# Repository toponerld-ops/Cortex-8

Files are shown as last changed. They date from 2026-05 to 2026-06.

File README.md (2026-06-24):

<div align="center">

# **Cortex-8**

**8-in-1 AIO Flight Controller for X8 Coaxial Racing Drones**

**High-performance X8 coaxial FPV racing drone flight controller**  everything integrated on a single 61×65mm board.

</div>

---

ZINE-Cortex-8

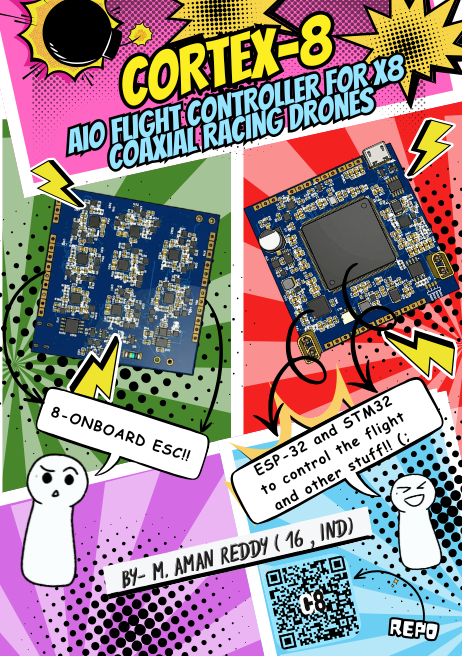
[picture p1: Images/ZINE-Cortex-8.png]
ZINE


## *Project Visionnnn*

This is Gen 5 of my custom flight controller journey.
I keep building these things because I genuinely want to see how far one guy can push drone hardware before reality kicks in. The long-term plan is straightforward: design flight controllers from scratch, cram every possible subsystem onto one tiny board, and eventually move into AI-powered autonomous flight (the "drones that think for themselves" thing is just too cool no Skynet though, promise).
Cortex-8 is the latest step in that direction a completely over-the-top 8-in-1 All-In-One flight controller built specifically for X8 coaxial FPV racing drones.

## *Features*

MCU: STM32H743 running at 480MHz

Wireless: ESP32-S3 (WiFi + BLE + ELRS support)

ESCs: 8x integrated high-current drivers for X8 coaxial setup

Battery: Dual 2S LiPo with software + hardware switchable series/parallel (7.4V or 14.8V)

Charging: Up to 140W USB-PD EPR at 20V

Blackbox: 128MB QSPI flash

PCB: 61×65mm 8-layer HDI, ENIG finish, X-Ray inspected

Bonus: Built-in crash locator so you’ll (hopefully) never lose the drone

---

BOM

|No.|Quantity|Comment |Designator |Footprint |Value |Manufacturer Part |Manufacturer |Supplier Part|Supplier|JLCPCB Price|JLCPCB Stock|
|---|---|---|---|---|---|---|---|---|---|---|---|
|1  |84 |100nF |C1,C2,C5,C6,C8,C9,C10,C14,C15,C16,C17,C18,C19,C20,C21,C23,C25,C26,C29,C30,C31,C32,C33,C37,C39,C41,C43,C45,C47,C49,C51,C53,C55,C57,C59,C61,C63,C65,C67,C69,C72,C74,C76,C77,C79,C80,C81,C85,C87,C88,C89,C93,C95,C96,C97,C101,C103,C104,C105,C109,C110,C111,C115,C117,C118,C119,C123,C125,C126,C127,C131,C133,C134,C135,C139,C140,C156,C158,C159,C161,C162,C163,C164,C166|C0603 |100nF |CC0603KRX7R9BB104 |YAGEO(国巨) |C14663 |LCSC |0.0026 |14950789 |
|2  |7 |1uF |C3,C7,C35,C36,C38,C73,C75 |C0402 |1uF |0402X105K250NT |FH(风华) |C967571 |LCSC |0.0018 |91670 |
|3  |4 |2.2uF |C4,C11,C12,C71 |C0603 |2.2uF |CL10A225KO8NNNC |SAMSUNG(三星) |C23630 |LCSC |0.0014 |1034471 |
|4  |1 |220uF |C13 |CAP-SMD_BD8.0-L8.3-W8.3-LS9.3-FD |220uF |RVT220UF35V67RV0024 |KNSCHA(科尼盛) |C2836441 |LCSC |0.012 |81517 |
|5  |2 |47uF |C22,C24 |C0603 |47uF  |GRM188R60J476ME15D |muRata(村田) |C140782 |LCSC |0.0212 |194067 |
|6  |39 |10uF |C27,C28,C34,C40,C42,C44,C46,C48,C50,C52,C54,C56,C58,C60,C62,C64,C66,C68,C70,C78,C86,C94,C102,C116,C124,C132,C141,C142,C143,C144,C145,C146,C149,C150,C151,C154,C157,C160,C165 |C0805 |10uF  |GRM21BR71E106KEBHL |muRata(村田) |C5299751 |LCSC |0.0243 |1523 |
|7  |24 |10nF |C82,C83,C84,C90,C91,C92,C98,C99,C100,C106,C107,C108,C112,C113,C114,C120,C121,C122,C128,C129,C130,C136,C137,C138 |C0603 |10nF  |CC0603KRX7R9BB103 |YAGEO(国巨) |C100042 |LCSC |0.0009 |17534 |
|8  |3 |47nF |C147,C148,C153 |C0402 |47nF  |0402B473K100CT |Walsin(华新科) |C301947 |LCSC |0.0005 |15 |
|9  |1 |4.7uF |C152 |C0603 |4.7uF |CL10A475KP8NNNC |SAMSUNG(三星) |C1705 |LCSC |0.0019 |96271 |
|10 |1 |2.2uF |C155 |C0603 |2.2uF |CC0603X5R25V225KN |TORCH(火炬) |C53084536 |LCSC |0.0031 |26321 |
|11 |2 |XT30UPB-M |CN1,CN2 |CONN-TH_XT30UPB-M | |XT30UPB-M |AMASS(艾迈斯) |C428721 |LCSC |0.0388 |59450 |
|12 |1 |SMBJ15A |D1 |SMB_L4.6-W3.6-LS5.3-RD | |SMBJ15A |Hottech(合科泰) |C49238213 |LCSC |0.0042 |2414 |
|13 |2 |PRTR5V0U2X |D4,D7 |SOT-143_L2.9-W1.3-P1.92-LS2.3-BL | |PRTR5V0U2X |GOODWORK(固得沃克) |C21713980 |LCSC |0.0068 |9185 |
|14 |1 |SMBJ24A |D6 |SMB_L4.5-W3.7-LS5.4-RD | |SMBJ24A |FOSAN(富捷/富信) |C5353267 |LCSC |0.0061 |6752 |
|15 |1 |HX PZ1.27-1x4P WT |H1 |HDR-SMD_4P-P1.27-H-M-W7.8 | |HX PZ1.27-1x4P WT |hanxia(韩下) |C46061654 |LCSC |0.0118 |4282 |
|16 |1 |SCBW100505U100T |L1 |L0402 | |SCBW100505U100T |Yanchuang(研创) |C53063739 |LCSC |0.0006 |10000 |
|17 |2 |2.2uH |L2,L3 |IND-SMD_L4.0-W4.0_LQH44PN2R2MP0L |2.2uH |SMNR4020-2.2UH |SXN(顺翔诺) |C135262 |LCSC |0.0087 |51409 |
|18 |1 |4.7uH |L4 |L0603 |4.7uH |CKCW0603H-4.7uH/K |CENKER(岑科) |C19188762 |LCSC |0.0118 |1569 |
|19 |1 |1uH |L5 |IND-SMD_L2.0-W1.6_MTQH201610S |1uH |APH201612C1R0MP01 |APV(爱普微) |C42455319 |LCSC |0.007 |2205 |
|20 |1 |16MHz |OSC1 |OSC-SMD_4P-L3.2-W2.5_OW2EL89CANUNFAYLC|16MHz |OW2EL89CENUXFMYLC-16M |YXC(扬兴晶振) |C22434891 |LCSC |0.1652 |2407 |
|21 |54 |CSD17313Q2 |Q1,Q2,Q3,Q4,Q5,Q6,Q7,Q10,Q11,Q12,Q13,Q14,Q15,Q16,Q17,Q18,Q19,Q20,Q21,Q22,Q23,Q24,Q25,Q26,Q27,Q28,Q29,Q30,Q31,Q32,Q33,Q34,Q35,Q36,Q37,Q38,Q39,Q40,Q41,Q42,Q43,Q44,Q45,Q46,Q47,Q48,Q49,Q50,Q51,Q52,Q53,Q54,Q55,Q56 |WSON-6_L2.0-W2.0-P0.65-TL_CSD17313Q2  | |CSD17313Q2 |TI(德州仪器) |C2863837 |LCSC |0.0495 |7352 |
|22 |1 |2N7002 |Q8 |SOT-23-3_L2.9-W1.5-P1.90-LS2.6-BR | |2N7002 |TECH PUBLIC(台舟) |C28646312 |LCSC |0.0033 |3290 |
|23 |1 |SI2323DS(UMW) |Q9 |SOT-23-3_L2.9-W1.3-P0.95-LS2.4-BR | |SI2323DS(UMW) |UMW(友台半导体) |C5346821 |LCSC |0.0078 |12554 |
|24 |1 |560kΩ |R1 |R0603 |560kΩ |RC0603FR-07560KL |YAGEO(国巨) |C137699 |LCSC |0.0003 |109432 |
|25 |2 |10kΩ |R2,R9 |R0402 |10kΩ  |AC0402FR-0710KL |YAGEO(国巨) |C144807 |LCSC |0.0003 |132 |
|26 |6 |22Ω |R3,R4,R5,R6,R7,R8 |R0402 |22Ω |RC0402FR-0722RL |YAGEO(国巨) |C114765 |LCSC |0.0002 |124 |
|27 |1 |267kΩ |R10 |R0603 |267kΩ |FRC0603F2673TS |FOJAN(富捷) |C2998118 |LCSC |0.0003 |26827 |
|28 |7 |100kΩ |R11,R16,R17,R21,R125,R126,R131 |R0402 |100kΩ |RC0402FR-07100KL |YAGEO(国巨) |C60491 |LCSC |0.0002 |5492 |
|29 |1 |10Ω |R12 |RES-SMD_L5.8-W2.2 |10Ω |SMM02070C1009FBP00 |VISHAY(威世) |C5224088 |LCSC |0.0221 |2519 |
|30 |2 |10mΩ |R13,R14 |R0805 |10mΩ  |HoJLR0805-1/2W-10mR-1%|Milliohm(毫欧) |C41427589 |LCSC |0.0064 |3107 |
|31 |7 |10kΩ |R15,R118,R119,R123,R124,R132,R133 |R0402 |10kΩ  |RC0402FR-0710KL |YAGEO(国巨) |C60490 |LCSC |0.0002 |4 |
|32 |3 |100Ω |R18,R19,R20 |R0402 |100Ω  |RC0402FR-07100RL |YAGEO(国巨) |C106232 |LCSC |0.0002 |33 |
|33 |48 |10kΩ |R22,R23,R24,R25,R26,R27,R34,R35,R36,R37,R38,R39,R46,R47,R48,R49,R50,R51,R58,R59,R60,R61,R62,R63,R70,R71,R72,R73,R74,R75,R82,R83,R84,R85,R86,R87,R94,R95,R96,R97,R98,R99,R106,R107,R108,R109,R110,R111 |R0402 |10kΩ  |CR0402FF1002G |LIZ(丽智电子) |C100196 |LCSC |0.0002 |3518 |
|34 |48 |2.2Ω |R28,R29,R30,R31,R32,R33,R40,R41,R42,R43,R44,R45,R52,R53,R54,R55,R56,R57,R64,R65,R66,R67,R68,R69,R76,R77,R78,R79,R80,R81,R88,R89,R90,R91,R92,R93,R100,R101,R102,R103,R104,R105,R112,R113,R114,R115,R116,R117 |R0402 |2.2Ω  |RMC04022.21%N |Tyohm(幸亚电阻) |C325532 |LCSC |0.0006 |585 |
|35 |2 |15kΩ |R120,R121 |R0402 |15kΩ  |RC0402FR-0715KL |YAGEO(国巨) |C114761 |LCSC |0.0002 |2846 |
|36 |1 |6.04kΩ |R122 |R0402 |6.04kΩ|FRC0402F6041TS |FOJAN(富捷) |C2998182 |LCSC |0.0003 |105693 |
|37 |1 |100Ω |R127 |R0402 |100Ω  |0402WGJ0101TCE |UNI-ROYAL(厚声) |C25138 |LCSC |0.0002 |8 |
|38 |1 |2.2kΩ |R128 |R0402 |2.2kΩ |0402WGJ0222TCE |UNI-ROYAL(厚声) |C25933 |LCSC |0.0002 |24 |
|39 |1 |294Ω |R129 |R0402 |294Ω  |0402WGF2940TCE |UNI-ROYAL(厚声) |C270618 |LCSC |0.0002 |2875 |
|40 |1 |127kΩ |R130 |R0805 |127kΩ |FRC0805F1273TS |FOJAN(富捷) |C2974033 |LCSC |0.0005 |133787 |
|41 |3 |Test-Point |TP1,TP2,TP3 |Test-Point-0.5mm | | | | | | | |
|42 |1 |STM32H743BIT6 |U1 |LQFP-208_L28.0-W28.0-P0.50-LS30.0-BL  | |STM32H743BIT6 |ST(意法半导体) |C89418 |LCSC |1.9319 |205 |
|43 |1 |W25Q128JWSIQ |U2 |SOIC-8_L5.3-W5.3-P1.27-LS8.0-BL | |W25Q128JWSIQ |Winbond(华邦) |C2763561 |LCSC |0.6874 |468 |
|44 |1 |ICM-42688-P |U3 |LGA-14_L3.0-W2.5-P0.50-TL | |ICM-42688-P |TDK InvenSense(应美盛)|C1850418 |LCSC |2.1188 |2886 |
|45 |1 |ICM-20602 |U4 |LGA-16_L3.0-W3.0-P0.50-BL | |ICM-20602 |TDK InvenSense(应美盛)|C97633 |LCSC |0.927 |8778 |
|46 |1 |74LVC1G08GV |U5 |SOT-23-5_L3.0-W1.7-P0.95-LS2.8-BL | |74LVC1G08GV |MDD(辰达半导体) |C53185136 |LCSC |0.0106 |2962 |
|47 |1 |74LVC1G04GV |U6 |SOT-23-5_L2.9-W1.6-P0.95-LS2.7-BR | |74LVC1G04GV |TECH PUBLIC(台舟) |C19829589 |LCSC |0.008 |5360 |
|48 |1 |TLV3201AIDCKT |U7 |SOT-353_L2.0-W1.2-P0.65-LS2.1-BL-1 | |TLV3201AIDCKT |TI(德州仪器) |C133590 |LCSC |0.0523 |139 |
|49 |1 |LM4040C25FTA |U8 |SOT-23-3_L2.9-W1.3-P1.90-LS2.4-BR | |LM4040C25FTA |DIODES(美台) |C460607 |LCSC |0.0625 |622 |
|50 |2 |LM74610QDGKRQ1 |U9,U10 |VSSOP-8_L3.0-W3.0-P0.65-LS5.0-BL | |LM74610QDGKRQ1 |TI(德州仪器) |C2649431 |LCSC |0.229 |1900 |
|51 |2 |INA240A2PW |U11,U12 |TSSOP-8_L4.4-W3.0-P0.65-LS6.4-BR | |INA240A2PW |TI(德州仪器) |C1346461 |LCSC |0.5124 |2 |
|52 |1 |TPS62840DLCR |U13 |VSON-8_L2.0-W1.5-P0.50-BL | |TPS62840DLCR |TI(德州仪器) |C2071859 |LCSC |0.2608 |69 |
|53 |1 |TPS62170QDSGTQ1 |U14 |WSON-8_L2.0-W2.0-P0.50-TL-EP | |TPS62170QDSGTQ1 |TI(德州仪器) |C2071903 |LCSC |0.2846 |90 |
|54 |1 |TPS3840PL33DBVR |U15 |SOT-23-5_L2.9-W1.6-P0.95-LS2.8-BR | |TPS3840PL33DBVR |TI(德州仪器) |C6290353 |LCSC |0.2382 |85 |
|55 |1 |SM02B-GHS-TB(LF)(SN) |U16 |CONN-SMD_SM02B-GHS-TB-LF-SN | |SM02B-GHS-TB(LF)(SN)  |JST |C189893 |LCSC |0.0219 |5447 |
|56 |8 |FD6288Q |U17,U18,U19,U20,U21,U22,U23,U24 |QFN-24_L4.0-W4.0-P0.50-BL-EP2.6 | |FD6288Q |Fortior Tech(峰岹) |C328453 |LCSC |0.1281 |972 |
|57 |1 |CH224K |U25 |ESSOP-10_L4.9-W3.9-P1.0-LS6.0-TL-EP | |CH224K |WCH(南京沁恒) |C970725 |LCSC |0.0913 |10052 |
|58 |1 |BQ25798RQMR |U26 |QFN-29_L4.0-W4.0-P0.40-TL-BQ25792RQMR | |BQ25798RQMR |TI(德州仪器) |C2876593 |LCSC |0.4014 |5387 |
|59 |1 |ESP32-S3FN8 |U27 |QFN-56_L7.0-W7.0-P0.40-TL-EP4.0 | |ESP32-S3FN8 |ESPRESSIF(乐鑫) |C2913196 |LCSC |0.5269 |1714 |
|60 |1 |TYPE-C 16PIN 3MD(385)|USB1 |USB-C-SMD_TYPE-C16PIN | |TYPE-C 16PIN 3MD(385) |SHOU HAN(首韩) |C2858270 |LCSC |0.0193 |28089 |

# Cortex-8 Firmware

The Cortex-8 runs on Betaflight 4.5.x, but it features a custom target that I developed specifically for the stm32h743. If you're interested in checking it out, you can find the complete target in /firmware/targets/CORTEX8/.

## Building the Firmware (For Windows)

# Clone Betaflight
git clone https://github.com/betaflight/betaflight
cd betaflight

# Copy Cortex-8 target into the source tree
cp -r /path/to/Cortex-8/firmware/targets/CORTEX8 src/main/target/CORTEX8

# Build
make CORTEX8

After this, the compiled .hex file will be located in the obj/ directory.

### Flashing

**Using SWD (recommended for the first flash):**
1. Connect the st-link v2/v3 to the 4 pin 1.27mm SWD header on the top layer.
2. The pinout is vcc — swdio — swclk — gnd.
3. Open STM32CubeProgrammer.
4. Connect via st-link.
5. Load the hex file and click program.

**Using DFU (for any subsequent flashes):**
1. Hold boot0 to 3.3v while plugging in USB-C.
2. The board will appear as STM32 bootloader in Device Manager.
3. Open Betaflight Configurator's firmware flasher.
4. Load CORTEX8.hex and flash it.
It’s much faster once the bootloader is already installed.
---

### How to Assemble the Cortex-8 FC

# *Step-by-Step*

Manufacture the PCB,
Upload the gerbers from the /gerbers folder to JLCPCB.

Order Components,
Order the components using BOM provided.

Flash the Firmware,
First, connect the SWD pins of the STM32 to a FTDI flasher. flash via SWD, then you can use DFU for updates. Set the board target as custom STM32H743 in Betaflight.

Batteries & Power,
- **PRECAUTION:Before connecting the battery check your surroundings for safty**
  
Connect the two 2S LiPos using XT30. The board starts in parallel (7.4V) by default. The STM32 can switch to series (14.8V), but there’s a hardware interlock to stop accidental shorting of the batteries. USB-PD charging is handled automatically.

Motors,
Solder 20AWG silicone wire to the phase pads on the edges (3 pads per motor). Left side = M1/M3/M5/M7, right side = M2/M4/M6/M8.

FPV & Extras,
The OpenFPV camera fits on the 30.5×30.5mm holes. The crash locator uses a small backup battery and sends BLE beacons via the ESP32 when the main power is lost.

## **IMAGES**

TOP PCB 3D

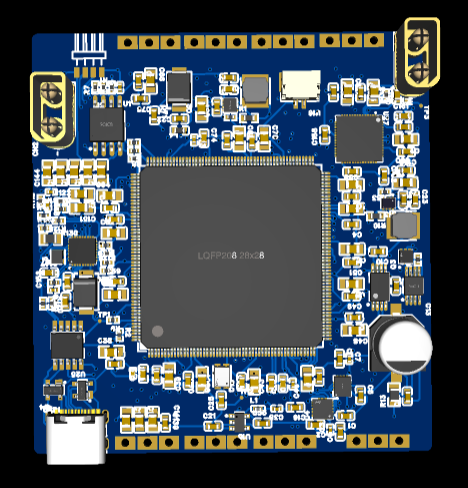
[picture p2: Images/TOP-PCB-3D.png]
TOP-PCB-3D


BOTTOM PCB 3D

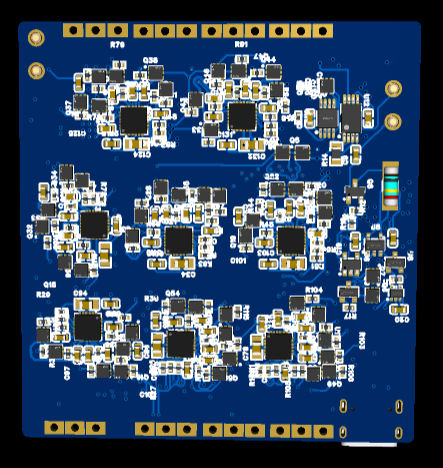
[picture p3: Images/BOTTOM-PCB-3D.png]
BOTTOM-PCB-3D


TOP LAYER TRACE

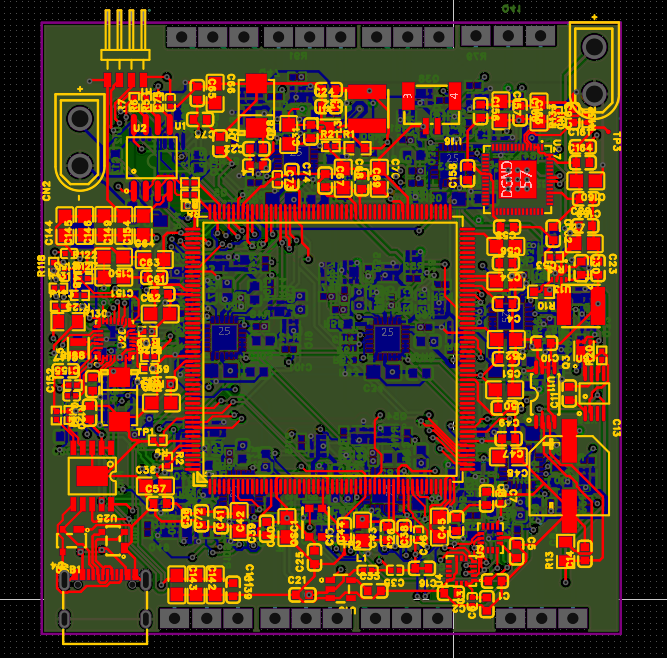
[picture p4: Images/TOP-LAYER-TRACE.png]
TOP-LAYER-TRACE


INNER LAYER 1

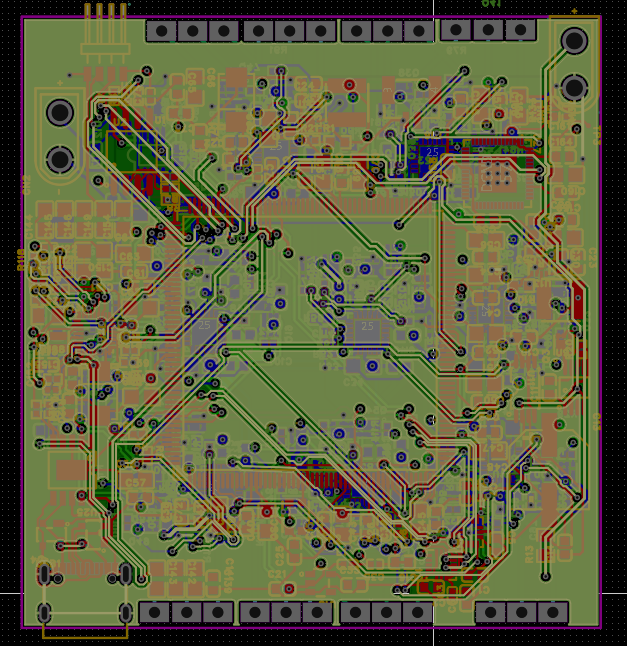
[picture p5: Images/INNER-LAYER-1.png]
INNER-LAYER-1


INNER LAYER 2

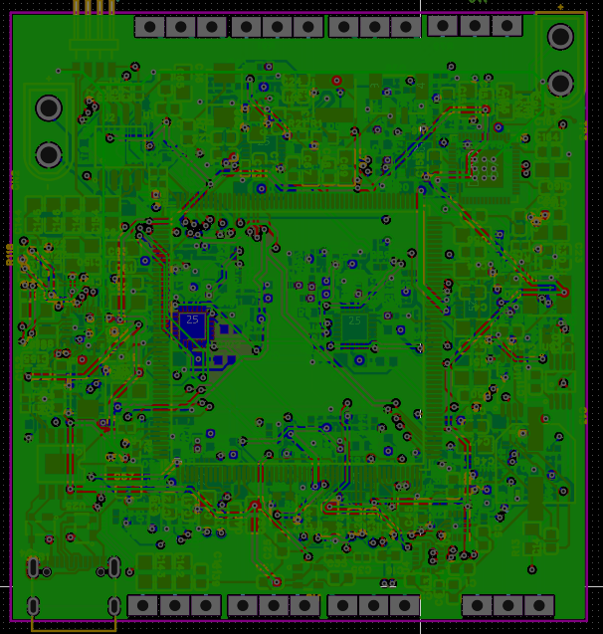
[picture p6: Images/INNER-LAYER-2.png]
INNER-LAYER-2


INNER LAYER 3

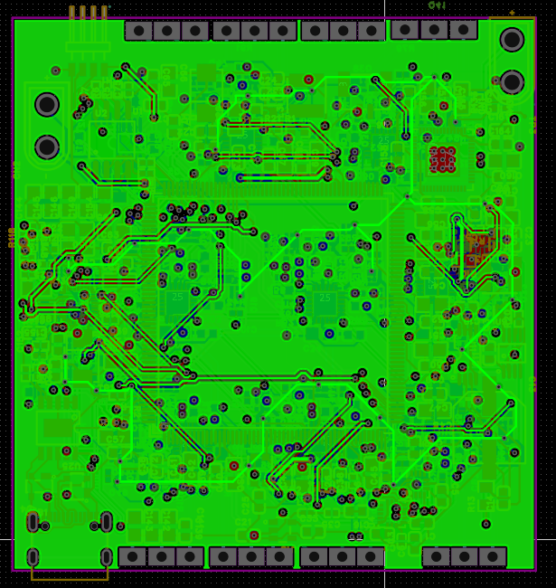
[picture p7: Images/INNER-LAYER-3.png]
INNER-LAYER-3


INNER LAYER 4

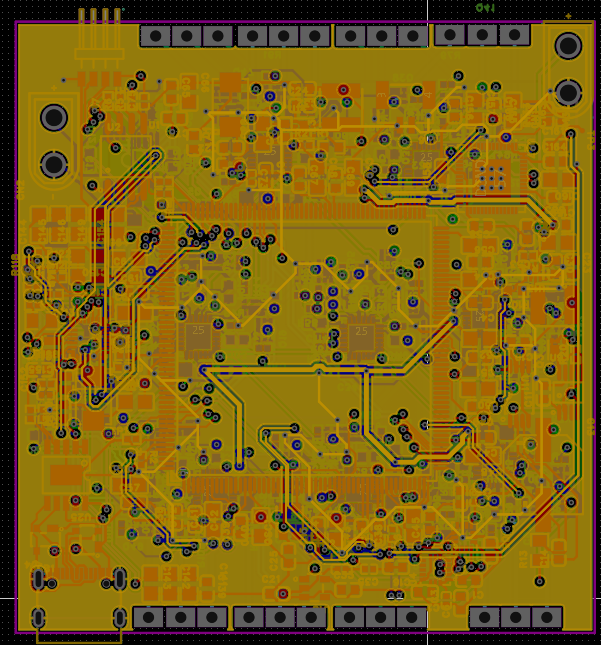
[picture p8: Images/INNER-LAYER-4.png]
INNER-LAYER-4


INNER LAYER 5

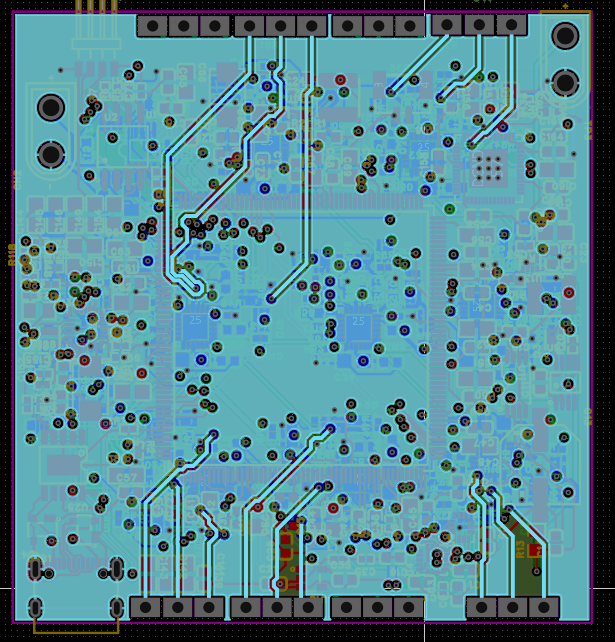
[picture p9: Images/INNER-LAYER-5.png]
INNER-LAYER-5


INNER LAYER 6

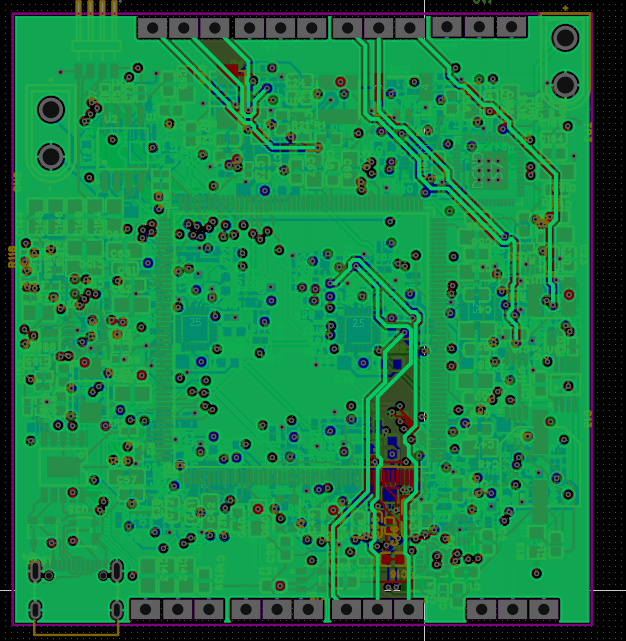
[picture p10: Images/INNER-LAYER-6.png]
INNER-LAYER-6


BOTTOM LAYER TRACE

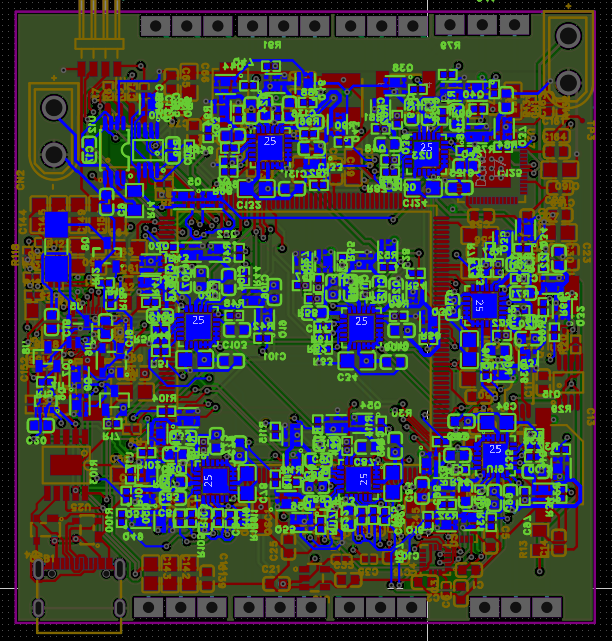
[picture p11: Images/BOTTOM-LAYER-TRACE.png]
BOTTOM-LAYER-TRACE


Designed by Muduganti Aman Reddy | Hackclub

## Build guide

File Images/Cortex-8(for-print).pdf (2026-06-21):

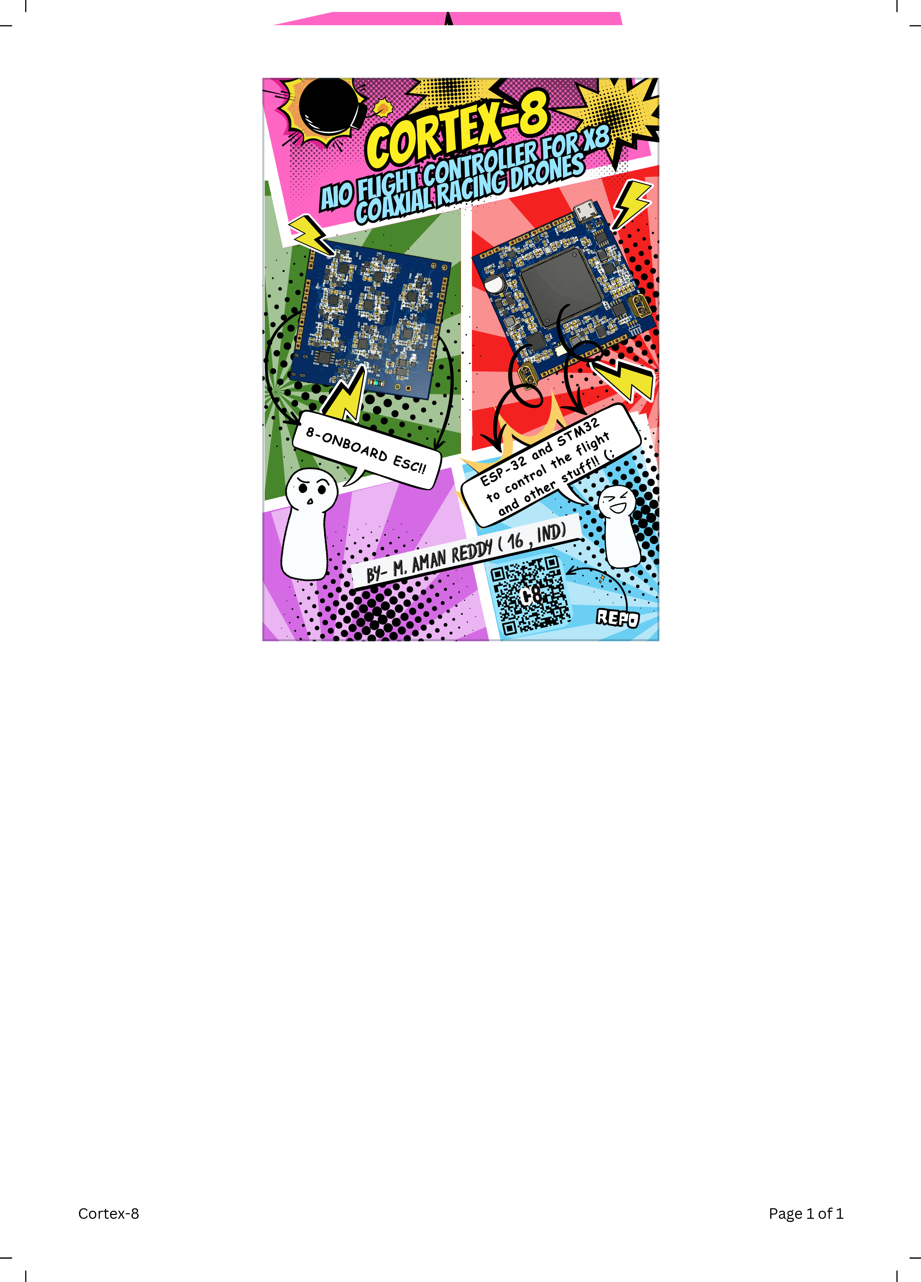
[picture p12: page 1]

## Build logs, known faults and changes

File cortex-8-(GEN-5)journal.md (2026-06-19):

# CORTEX-8 — Journal Export

- Exported at: 2026-06-19T15:39:32Z
- Project ID: 1067
- Entries: 63

## Entry 1
- ID: 1228
- Author: toponerld
- Created At: 2026-04-05T12:04:29Z

### Content

soo started the sch of the board and did sm researchig i have a few probs that ill fix later made sm progress
Screenshot 2026-04-05 172329.png

### Recording Links

- https://public.lapse-hackclub.link/timelapses/6jMfzRBHHVCS/timelapse-6jMfzRBHHVCS.mp4

## Entry 2
- ID: 1638
- Author: toponerld
- Created At: 2026-04-10T06:05:55Z

### Content

i cross checked the pins and analysed the max out put and the size charts so that i can fit all my components i had multiple windows open and cld share only one will check the next journal have to do bit more research


### Recording Links

- https://public.lapse-hackclub.link/timelapses/5mZUVrlAqrgS/timelapse-5mZUVrlAqrgS.mp4

## Entry 3
- ID: 1640
- Author: toponerld
- Created At: 2026-04-10T06:58:35Z

### Content

soooo umm i almost completed joting all the pins of the esp32 since im doin the pcb on a very tight space which also includes 8 escs so deciding where everything shd go in the final pcb next is the stm. its a random ss idk wt to put


### Recording Links

- https://public.lapse-hackclub.link/timelapses/4FbfQcJ-V51w/timelapse-4FbfQcJ-V51w.mp4

## Entry 4
- ID: 1757
- Author: toponerld
- Created At: 2026-04-11T11:01:01Z

### Content

making the sch for the fc, took sm time to understand how to Add Hierarchical Labels eventually figured it out and to clarify in the lapse when u see my cursor just moving here and there i was adding net lables but since when u open sch settings it opens in an another window 


### Recording Links

- https://public.lapse-hackclub.link/timelapses/PoMJecg4o_60/timelapse-PoMJecg4o_60.mp4

## Entry 5
- ID: 1779
- Author: toponerld
- Created At: 2026-04-11T16:24:34Z

### Content

i switched to easyeda forr better library's and im new to that shi so gonna take some time to adjust to it so started the sch again
Screenshot 2026-04-11 215417.png

### Recording Links

- https://public.lapse-hackclub.link/timelapses/MAulKlX61qXN/timelapse-MAulKlX61qXN.mp4

## Entry 6
- ID: 1795
- Author: toponerld
- Created At: 2026-04-11T18:04:23Z

### Content

sooo i almost completed the battery block this is taking a lot more time than i expected so for tomorrow ill try to finish atleast half of it kinda getting used to it but looking at the data sheets is taking time too
Screenshot 2026-04-11 233402.png

### Recording Links

- https://public.lapse-hackclub.link/timelapses/4zrOwDMnkmM1/timelapse-4zrOwDMnkmM1.mp4

## Entry 7
- ID: 1801
- Author: toponerld
- Created At: 2026-04-11T18:42:19Z

### Content

sooo i did most of the connections it was a bit confusing but i figured it out using the data sheets im glad i switched to easyeda now all thats left is to connect the power block to the stm32
Screenshot 2026-04-12 001153.png

### Recording Links

- https://public.lapse-hackclub.link/timelapses/mEVI3-77TItn/timelapse-mEVI3-77TItn.mp4

## Entry 8
- ID: 1812
- Author: toponerld
- Created At: 2026-04-11T19:44:54Z

### Content

completed the battery block had a bit of confusion with the xt30 connectors and the net ports but figured everything and its done
Screenshot 2026-04-12 011443.png

### Recording Links

- https://public.lapse-hackclub.link/timelapses/j6-ipeWDboKf/timelapse-j6-ipeWDboKf.mp4

## Entry 9
- ID: 3175
- Author: toponerld
- Created At: 2026-04-21T08:51:28Z

### Content

ummm so i finished placing most of my components but most of them were out of stock and had to find replacements and look at their data sheets and i accidentally clicked end instead of resume  
Screenshot 2026-04-21 142104.png

### Recording Links

- https://public.lapse-hackclub.link/timelapses/ANK_b-zQlaBn/timelapse-ANK_b-zQlaBn.mp4

## Entry 10
- ID: 3187
- Author: toponerld
- Created At: 2026-04-21T10:21:38Z

### Content


did sm wiring and checked the data sheets for the next steps imma check more of the pins later and thats it

## Entry 11
- ID: 3524
- Author: toponerld
- Created At: 2026-04-23T07:31:21Z

### Content

did alot of research in call with krish and did a lot more research for the ground station for the drone ig its gonna take a lot of money for the groundstation 

idk what ss to keep for research

### Recording Links

- https://public.lapse-hackclub.link/timelapses/vDA6t_Qalmu5/timelapse-vDA6t_Qalmu5.mp4

## Entry 12
- ID: 9290
- Author: toponerld
- Created At: 2026-05-26T04:45:05Z

### Content

started the power block its soooo confusing but ill have to pull through wish me luckk hope ill complete this soon
Screenshot 2026-05-26 101445.png

### Recording Links

- https://public.lapse-hackclub.link/timelapses/wyykcDoh7P_6/timelapse-wyykcDoh7P_6.mp4
- https://public.lapse-hackclub.link/timelapses/fHQlYi5-aYEJ/timelapse-fHQlYi5-aYEJ.mp4

## Entry 13
- ID: 9332
- Author: toponerld
- Created At: 2026-05-26T10:58:43Z

### Content

I just realised that changing the value of a cap or a resistor or anything will not change its footprint now i have to change every resistor cap and inductor i placed wish me luck 
Screenshot 2026-05-26 162814.png
Screenshot 2026-05-26 154131.png
Screenshot 2026-05-26 155002.png

### Recording Links

- https://public.lapse-hackclub.link/timelapses/nekmbHjiDxzb/timelapse-nekmbHjiDxzb.mp4

## Entry 14
- ID: 9619
- Author: toponerld
- Created At: 2026-05-27T10:03:31Z

### Content

sooo ive updated all the resistors inductors and caps every part now finnaly they have a footprint this was a huge lesson here are the ss for all the parts i replaced 
Screenshot 2026-05-27 140556.png
ohh looks like i cant paste 14 screenshots

### Recording Links

- https://public.lapse-hackclub.link/timelapses/bVV5VfXSvdcb/timelapse-bVV5VfXSvdcb.mp4

## Entry 15
- ID: 9625
- Author: toponerld
- Created At: 2026-05-27T10:51:46Z

### Content

I finished the battery block and the power block now im starting the ecs block which contains 8 gate drivers!! and 48x CSD17313Q2 motor FETs.!!

Screenshot 2026-05-27 162105.png
Screenshot 2026-05-27 162059.png
Screenshot 2026-05-27 162052.png

### Recording Links

- https://public.lapse-hackclub.link/timelapses/EtGdO5alh2ek/timelapse-EtGdO5alh2ek.mp4

## Entry 16
- ID: 9867
- Author: toponerld
- Created At: 2026-05-28T09:26:53Z

### Content

hmmm im a bit confused about the connections from the gate drivers to the fets and ive asked my friends too but none of dont seem to figure it out,hmmm have to do a bit more resarch on this


### Recording Links

- https://public.lapse-hackclub.link/timelapses/1SuL4X-1erth/timelapse-1SuL4X-1erth.mp4

## Entry 17
- ID: 9911
- Author: toponerld
- Created At: 2026-05-28T14:03:22Z

### Content

sooo i understood what i was doin wrong with the help of krish the goat!! so i was connecting 2 mosfets together instead of connecting them to the driver but fixed it!!
Screenshot 2026-05-28 193307.png

### Recording Links

- https://public.lapse-hackclub.link/timelapses/823QmB8zUmb-/timelapse-823QmB8zUmb-.mp4

## Entry 18
- ID: 9920
- Author: toponerld
- Created At: 2026-05-28T14:39:42Z

### Content

yeye ive almost completed the esc block and now i have 48 fets and 8 FD6288Q gate drivers so ive wired everything up and thats it for the ecs block next is the usb block
Screenshot 2026-05-28 200904.png
 but have to change the lables too

### Recording Links

- https://public.lapse-hackclub.link/timelapses/KEnmi0Q4PW4_/timelapse-KEnmi0Q4PW4_.mp4

## Entry 19
- ID: 9924
- Author: toponerld
- Created At: 2026-05-28T15:16:08Z

### Content

okay sooo the blk 5 is finished!!!!! ive finished the lables and now gonna start the blk 6 the usb block!!
Screenshot 2026-05-28 203700.png

### Recording Links

- https://public.lapse-hackclub.link/timelapses/n1dugfq_AvVL/timelapse-n1dugfq_AvVL.mp4

## Entry 20
- ID: 10209
- Author: toponerld
- Created At: 2026-05-29T18:14:24Z

### Content

yesterday i finished the blk 5 the esc so in this session i started the block 6 the usb block and placed almost every component i need next up is wiring 
Screenshot 2026-05-29 234407.png

### Recording Links

- https://public.lapse-hackclub.link/timelapses/JiXwQSWwBEa1/timelapse-JiXwQSWwBEa1.mp4

## Entry 21
- ID: 10351
- Author: toponerld
- Created At: 2026-05-30T09:04:37Z

### Content

looks like the parts i place were wrong so placing finding good alternatives and placing them all again 
Screenshot 2026-05-30 143423.png

### Recording Links

- https://public.lapse-hackclub.link/timelapses/gB0-7IEDqoTO/timelapse-gB0-7IEDqoTO.mp4

## Entry 22
- ID: 10360
- Author: toponerld
- Created At: 2026-05-30T10:33:17Z

### Content

started wriring the block 6 i do have sm confusion tho but will look into it w=hope ill finish this sooon 
Screenshot 2026-05-30 160214.png

### Recording Links

- https://public.lapse-hackclub.link/timelapses/qN2kBCENBClz/timelapse-qN2kBCENBClz.mp4

## Entry 23
- ID: 10463
- Author: toponerld
- Created At: 2026-05-30T17:58:36Z

### Content

so ive started wiring for the usb c in the BLK 6 ig i will finish the BLK 6 in the next session or in the next 2 sessions 
Screenshot 2026-05-30 232823.png

### Recording Links

- https://public.lapse-hackclub.link/timelapses/VK8As-OSBlEh/timelapse-VK8As-OSBlEh.mp4

## Entry 24
- ID: 10483
- Author: toponerld
- Created At: 2026-05-30T18:45:08Z

### Content

sooo did the main connections and looks like mass ngl but imm having doubts whether im doin this ryt i was disscussin with my friend and found new info 
Screenshot 2026-05-31 001448.png

### Recording Links

- https://public.lapse-hackclub.link/timelapses/m7vXRtY4G0Da/timelapse-m7vXRtY4G0Da.mp4

## Entry 25
- ID: 10614
- Author: toponerld
- Created At: 2026-05-31T08:33:22Z

### Content

finished block 6 and so the usb part is done so next is the esp32 block ig will have to finish it and i forgot to resume my lapse
Screenshot 2026-05-31 140306.png

### Recording Links

- https://public.lapse-hackclub.link/timelapses/JROiBK40ZbsW/timelapse-JROiBK40ZbsW.mp4

## Entry 26
- ID: 10619
- Author: toponerld
- Created At: 2026-05-31T09:30:38Z

### Content

did all checks for block6 now moving to block 7 the esp block now im scared cause i might make a lot mistakes 
Screenshot 2026-05-31 150023.png

### Recording Links

- https://public.lapse-hackclub.link/timelapses/xlPZQ9Oz_vwo/timelapse-xlPZQ9Oz_vwo.mp4

## Entry 27
- ID: 10628
- Author: toponerld
- Created At: 2026-05-31T10:22:27Z

### Content

sooo im understanding the basics of the stm32 im using understanding how Low-speed external clock generated from a crystal/ceramic resonator work 


### Recording Links

- https://public.lapse-hackclub.link/timelapses/yGMwgxrPL3pS/timelapse-yGMwgxrPL3pS.mp4

## Entry 28
- ID: 10673
- Author: toponerld
- Created At: 2026-05-31T15:20:22Z

### Content

did alot of researchh for the stm32 and learned alot abt itt and placed most of the components in need 
Screenshot 2026-05-31 205005.png

### Recording Links

- https://public.lapse-hackclub.link/timelapses/9XwQNsmRzC6u/timelapse-9XwQNsmRzC6u.mp4

## Entry 29
- ID: 10955
- Author: toponerld
- Created At: 2026-06-01T18:23:44Z

### Content

soo ive done a bit of wiring butt omggg the stm32 data sheet is soo complexx i dont understand itt :(((


### Recording Links

- https://public.lapse-hackclub.link/timelapses/yqSipE4cXhMh/timelapse-yqSipE4cXhMh.mp4

## Entry 30
- ID: 11094
- Author: toponerld
- Created At: 2026-06-02T09:45:46Z

### Content

did wiring for the stm32 its sooo confusingg and my claude decided to stop working and so i looked at the pin wiring can crosschecked and wired 


### Recording Links

- https://public.lapse-hackclub.link/timelapses/ZBARhUmGUQMZ/timelapse-ZBARhUmGUQMZ.mp4

## Entry 31
- ID: 11187
- Author: toponerld
- Created At: 2026-06-02T17:59:41Z

### Content

learned more about the stm32 onboard chip its getting more and more complicated ima gonna check for sources where i can understand it easier
Screenshot 2026-06-02 232921.png

### Recording Links

- https://public.lapse-hackclub.link/timelapses/mQ7OlbpsuqEC/timelapse-mQ7OlbpsuqEC.mp4
- https://public.lapse-hackclub.link/timelapses/x3i1pxfbdAy5/timelapse-x3i1pxfbdAy5.mp4

## Entry 32
- ID: 11399
- Author: toponerld
- Created At: 2026-06-03T16:15:18Z

### Content

Screenshot 2026-06-03 214403.png completed most of the wiring for the stm32 now have a few doubts in wiring the W25Q128JWSIQ and OSC1

### Recording Links

- https://public.lapse-hackclub.link/timelapses/AzcMBnCDQKkB/timelapse-AzcMBnCDQKkB.mp4

## Entry 33
- ID: 11646
- Author: toponerld
- Created At: 2026-06-04T16:27:47Z

### Content

completed the block one STM32 and now gonna go to the ESP32 block and now imma analyze the esp32 nooo


### Recording Links

- https://public.lapse-hackclub.link/timelapses/8QC9RmkDXWPV/timelapse-8QC9RmkDXWPV.mp4

## Entry 34
- ID: 11660
- Author: toponerld
- Created At: 2026-06-04T17:37:47Z

### Content

checked all the pins that i wired for the stm32 and the other parts and removed all my warnings that we a prob


### Recording Links

- https://public.lapse-hackclub.link/timelapses/-bpGwWWV1j-g/timelapse--bpGwWWV1j-g.mp4

## Entry 35
- ID: 12049
- Author: toponerld
- Created At: 2026-06-06T14:42:59Z

### Content

started the esp block ig i will finish this soon and head to IMU block next the esp32 block is small


### Recording Links

- https://public.lapse-hackclub.link/timelapses/GiWF_jWL5tJz/timelapse-GiWF_jWL5tJz.mp4

## Entry 36
- ID: 12073
- Author: toponerld
- Created At: 2026-06-06T16:19:56Z

### Content

soooo ive finished all the schematicsss im done eith the IMU tooo so all thats left now is placing the net ports and connecting themm!! and then we cam move to the PCB!!! 



### Recording Links

- https://public.lapse-hackclub.link/timelapses/kMYLBgNZFS_J/timelapse-kMYLBgNZFS_J.mp4

## Entry 37
- ID: 12087
- Author: toponerld
- Created At: 2026-06-06T17:27:12Z

### Content

okayy soo ive adjusted my mistakes and learned that i shd  make pages instead of new sheets huhh so i had to shift everything to the pages and uploaded to sch now im disussing with my friend for finding the optimal and the most efficient placement for the resistors hehehe
Screenshot 2026-06-06 222633.png
<!-- Uploading Screenshot 2026-06-06 224554.png (36 KB)... Processing... -->

### Recording Links

- https://public.lapse-hackclub.link/timelapses/aOjTwtSl9MsH/timelapse-aOjTwtSl9MsH.mp4

## Entry 38
- ID: 12215
- Author: toponerld
- Created At: 2026-06-07T06:07:33Z

### Content

started the tracingg so now i gotta find the most efficient position for the d-shot blocks and now im thinking about the most effciect placement and im learning more about how i can use the esp32 for diff proposes, i got a crazy idea 


### Recording Links

- https://public.lapse-hackclub.link/timelapses/CYg1X_GLmuV8/timelapse-CYg1X_GLmuV8.mp4

## Entry 39
- ID: 12226
- Author: toponerld
- Created At: 2026-06-07T07:45:04Z

### Content

sooo ive placed alll the resistors and the components that go to the Stm 32 near it, so the best way to do this as far as i found out is to compare it to the sch and place them accordingly and now gonna move the to esp32 next or the dshot!


### Recording Links

- https://public.lapse-hackclub.link/timelapses/b1hkIsao4b0x/timelapse-b1hkIsao4b0x.mp4

## Entry 40
- ID: 12249
- Author: toponerld
- Created At: 2026-06-07T10:15:51Z

### Content


sooo ive placed all the components of the esp32 and the components of the IMU block together and started to arrange it on the 60 by 60mm pcb heheh

### Recording Links

- https://public.lapse-hackclub.link/timelapses/8GQgGoDpNLVt/timelapse-8GQgGoDpNLVt.mp4

## Entry 41
- ID: 12259
- Author: toponerld
- Created At: 2026-06-07T11:19:53Z

### Content

now placed the comopnents for ONE of the drivers uhhhhhhhh so much timeee so now i gotta do the 7 thats left so imma do those next and then ig i will add some more mods to it and start tracing, i tried to find some alternatives and looks like the alteratives are bigger so imma stick to the same driver


### Recording Links

- https://public.lapse-hackclub.link/timelapses/-4AWFqmuPo_h/timelapse--4AWFqmuPo_h.mp4

## Entry 42
- ID: 12262
- Author: toponerld
- Created At: 2026-06-07T11:52:41Z

### Content

completed the arrangement of another dshot and did some research on what all sensors i shd add cause i forgot tooo!!


### Recording Links

- https://public.lapse-hackclub.link/timelapses/b0BqGBdTrYdP/timelapse-b0BqGBdTrYdP.mp4

## Entry 43
- ID: 12279
- Author: toponerld
- Created At: 2026-06-07T13:25:22Z

### Content

sooo did more of the placements i think i might be cooked and im getting scared idk how to place the STM32 and found out that it too has masther and slave config which gives me more ideas heheh so have to finish it fast!!!


### Recording Links

- https://public.lapse-hackclub.link/timelapses/lfRwbbq2QjIE/timelapse-lfRwbbq2QjIE.mp4

## Entry 44
- ID: 12537
- Author: toponerld
- Created At: 2026-06-08T16:37:26Z

### Content

yooo finished placing the d-shots heheheheheh okay there is some more stuff left to put in and thenn i start tracing , uhhh this is gonna ba a nightmaree regretting life choises. Im putting alot of efforts in for this hoping this all will work out :)

Screenshot 2026-06-08 220634.png

### Recording Links

- https://public.lapse-hackclub.link/timelapses/0881pcqEG_nI/timelapse-0881pcqEG_nI.mp4
- https://public.lapse-hackclub.link/timelapses/fD8thK2hHXqj/timelapse-fD8thK2hHXqj.mp4

## Entry 45
- ID: 12798
- Author: toponerld
- Created At: 2026-06-09T16:41:16Z

### Content



okay so im almost done placing the components but this looks like helll to start wiring imm soo done with this PCB!!!

### Recording Links

- https://public.lapse-hackclub.link/timelapses/NTB5htw0C1fe/timelapse-NTB5htw0C1fe.mp4

## Entry 46
- ID: 13489
- Author: toponerld
- Created At: 2026-06-12T16:21:57Z

### Content

sooo ive changed the placement for the d-shot and it looks soo much better and ill do that for all the d-shot 
Screenshot 2026-06-10 213214.png

### Recording Links

- https://public.lapse-hackclub.link/timelapses/mc2IHoxCzUhy/timelapse-mc2IHoxCzUhy.mp4

## Entry 47
- ID: 13525
- Author: toponerld
- Created At: 2026-06-12T18:25:49Z

### Content

sooo did more arrangements for the d-shot and this will take a lot of time and i have to do the traces tooo!! 


### Recording Links

- https://public.lapse-hackclub.link/timelapses/syv2VhrfsycK/timelapse-syv2VhrfsycK.mp4

## Entry 48
- ID: 13909
- Author: toponerld
- Created At: 2026-06-14T07:53:17Z

### Content

sooo ive finished all the dshot placementss and now i have a few more components left!! and then il start tracing then it will be done!!


### Recording Links

- https://public.lapse-hackclub.link/timelapses/Q2vnsRMatmDU/timelapse-Q2vnsRMatmDU.mp4

## Entry 49
- ID: 13939
- Author: toponerld
- Created At: 2026-06-14T10:15:05Z

### Content

sooo finished the placementss noww all thats left is the tracess!! then its donee heheheh okay ive also set the DCR rules and the layer management setteing 


### Recording Links

- https://public.lapse-hackclub.link/timelapses/KJjDREwIt6YY/timelapse-KJjDREwIt6YY.mp4

## Entry 50
- ID: 13952
- Author: toponerld
- Created At: 2026-06-14T11:23:02Z

### Content

soo ive had a problem where when i start tracing in a diff layer it wld js pop back up on the top layer but Krish comes to the savee hehehe now i can trace and finisged the vbat primary less goo 


### Recording Links

- https://public.lapse-hackclub.link/timelapses/HxuOofwjNPZk/timelapse-HxuOofwjNPZk.mp4

## Entry 51
- ID: 14007
- Author: toponerld
- Created At: 2026-06-14T15:45:02Z

### Content

sooo ive done a lot of tracingg and lokks like i can finish this soon enough but i gotta lock in!!!!


### Recording Links

- https://public.lapse-hackclub.link/timelapses/W6FAk3VDa5ge/timelapse-W6FAk3VDa5ge.mp4

## Entry 52
- ID: 14038
- Author: toponerld
- Created At: 2026-06-14T17:23:33Z

### Content


sooo ive traced almost all pf the pwr laness and tracing iss sooo much easier than placng parts and now that i think about it 8 layers might be an over kill so ill be shifting it to 6 layers and ts is gonna be sinished soonn

### Recording Links

- https://public.lapse-hackclub.link/timelapses/W0VpX9PqLy8r/timelapse-W0VpX9PqLy8r.mp4

## Entry 53
- ID: 14248
- Author: toponerld
- Created At: 2026-06-15T14:15:23Z

### Content

sooo i did sm wiring started the signal pins and my M8 d-shot placement was cocked so now i have to wire everything again for the M8 d-shot 


### Recording Links

- https://public.lapse-hackclub.link/timelapses/3WyXd3VpZNvM/timelapse-3WyXd3VpZNvM.mp4

## Entry 54
- ID: 14260
- Author: toponerld
- Created At: 2026-06-15T15:35:15Z

### Content

uhhh i got soo much rage baited the placements for M7 and M8 all the components for these 2 d-shot thingys js decided to overlap on each other (heavy sob) so i have to do the placements again!! and the route everything again!! 


### Recording Links

- https://public.lapse-hackclub.link/timelapses/1zBWfnEGPJZC/timelapse-1zBWfnEGPJZC.mp4

## Entry 55
- ID: 14294
- Author: toponerld
- Created At: 2026-06-15T18:38:05Z

### Content

soo ive done more tracing and there is js a few more traces lefttt and this will be done!!! im very sscared 


### Recording Links

- https://public.lapse-hackclub.link/timelapses/fKRfjQGgzc9_/timelapse-fKRfjQGgzc9_.mp4

## Entry 56
- ID: 14559
- Author: toponerld
- Created At: 2026-06-16T16:02:00Z

### Content

soo ive done a lott of wiring and fixed some of the placements and im gonna finish it soon yeyey but i hope it wont get rejected huu im scaredd


### Recording Links

- https://public.lapse-hackclub.link/timelapses/XOXzCeQJlYFO/timelapse-XOXzCeQJlYFO.mp4

## Entry 57
- ID: 14575
- Author: toponerld
- Created At: 2026-06-16T17:10:05Z

### Content

uhhh looks like the top layer is donee yee finally yippeee so now all thats left is a few bottom traces and thats it!!! less goo andd this is a hell lot of vias 


### Recording Links

- https://public.lapse-hackclub.link/timelapses/_rvDfWO5k-gE/timelapse-_rvDfWO5k-gE.mp4

## Entry 58
- ID: 14597
- Author: toponerld
- Created At: 2026-06-16T18:34:06Z

### Content

okay sooo what i did was i traced more of the components and also traced the motor pins since they have a lot of current running on them i decided to go with thick traces which i didnt plan for before so had to make a few adjustments so that the traces fit there are just a few more traces left to do and this will be done and i can move to the zine page yeyey 


### Recording Links

- https://public.lapse-hackclub.link/timelapses/sULKZduF5xLG/timelapse-sULKZduF5xLG.mp4

## Entry 59
- ID: 14931
- Author: toponerld
- Created At: 2026-06-18T05:00:51Z

### Content

sooo ive did more traces but looks like i have sm prob with the drc but ill check that out later and in this session ive completed all the traces and i have a lot to improve but ill do that in the next generation of the board.


### Recording Links

- https://public.lapse-hackclub.link/timelapses/svPi2GIjfHlY/timelapse-svPi2GIjfHlY.mp4

## Entry 60
- ID: 14964
- Author: toponerld
- Created At: 2026-06-18T09:57:37Z

### Content

soo im almost donee last D-Shot!! left to tracee and sm other traces so like 15 traces left i think or less then the board will be done!!!


### Recording Links

- https://public.lapse-hackclub.link/timelapses/pN0DoXiWMdrt/timelapse-pN0DoXiWMdrt.mp4

## Entry 61
- ID: 14975
- Author: toponerld
- Created At: 2026-06-18T11:29:52Z

### Content

uhhhhh sooo ive done routing everything but forgot to place the motor pads now ill do that and it will be donee!!  
Screenshot 2026-06-18 165702.png
<!-- Uploading Screenshot 2026-06-18 165657.png (242 KB)... Processing... -->

### Recording Links

- https://public.lapse-hackclub.link/timelapses/2_9DUVcRyFh6/timelapse-2_9DUVcRyFh6.mp4

## Entry 62
- ID: 15217
- Author: toponerld
- Created At: 2026-06-19T13:08:45Z

### Content

okay finished the pcb and started the zine page design and the git hub modifications for my board and ill finish this project today!!


### Recording Links

- https://public.lapse-hackclub.link/timelapses/0xcZ_zLERDxf/timelapse-0xcZ_zLERDxf.mp4

## Entry 63
- ID: 15262
- Author: toponerld
- Created At: 2026-06-19T15:29:09Z

### Content

finished the git hub and the zine pagee and all thats left to so is upload all the files to the github and submit it!!!


### Recording Links

- https://public.lapse-hackclub.link/timelapses/4FPO0avWF2_Z/timelapse-4FPO0avWF2_Z.mp4

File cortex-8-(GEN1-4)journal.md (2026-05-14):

<!--
  This journal is auto generated by Stasis.
-->

# 3/25/2026 12 PM - more research and optimizing

_Time spent: 8h_

sooo my 35.5 by 36mm board is wayyyy to big for my 75mm whoop and i could not trace on the old board i had to use too many vias in a bad way so i did more research and am cutting the esc 30+ parts with 4 and trying to shrink it to 25.5mm by 25.5mm by retaining all features.To achieve the 25.5mm Whoop form factor while maintaining the high-bandwidth AI telemetry link (STM32H7 + ESP32-S3), I have moved to an 8-layer HDI (High-Density Interconnect) design. This allows for internal power planes and Via-in-Pad technology, which are necessary to manage the signal integrity of the 480MHz processor and the thermal dissipation of the 60A ESC in such a constrained volume. i dont have a pic for research so here is a random



# 3/24/2026 12 PM - soo replaced a lot of the components and started tracing

_Time spent: 5.8h_

after a lot of research on wts the best components to use and on how the pads on the chips work i started doin the pcb againn i completed the pwr traces and moving to the signal pins next wish me luck!!



# 3/22/2026 11 PM - FAHHH

_Time spent: 4.7h_

sooooo after a lot of banging my head and tryin to figure out why cant i trace above the esp i found out that even if the esp was on the other side we cant place anything in the antenna area.so i adjusted everything again and found out that custom symbols dont have pads so have to do then entire sch again.
Basically start from scratch thinkin to make a the pcb bigger and mould the frame around it basically a star shaped pcb 



# 3/22/2026 1 PM - finished planning and placing

_Time spent: 2.5h_

soo that many components and i misjudged how big the esp32 was it was taking up half of the 35 by 35mm board so i switch to 4 layers and i didnt start routing and im getting scared on how am gonna do it and its a very tight squeeze wish me luck 



# 3/22/2026 10 AM - Completed schematic

_Time spent: 8.4h_

okay so the schematic features 
FC
ESC
Gyro
OSD
VTX (add RTC6705)
ELRS receiver (ESP32)
AI link ESP-NOW (ESP32)
Current sensing (DRV8323RS)
idk if these count but im counting them cause it took a lot of time and it is my first time, the amount of errors i had was crazy i almost cried looking at them but at last it came to 0 yeye.i still dont know if this is shi or not unless some one tells me.



# 3/22/2026 10 AM - Custom symbols

_Time spent: 7.2h_

so it became an 8IN1 ill tell the features in the next journal and ill make it fit on an 35 by 35mm board since the compact size i had to create a lot of custom symbols which took a lot of time











# 3/21/2026 12 PM - More research and major redesign

_Time spent: 6h_

ok so a lot happened today. I was going back and forth trying to figure out the best components and i landed on something really really good.
so basically the old design had IR2104 gate drivers which wont fit on a 26x26mm board so i had to rethink everything. did a ton of research and found way better components.
new component list:

STM32G473CEU6 (same chip as the real Matrix FC)
ICM-42688-P (better gyro than MPU6000, more resistant to RF noise)
4x DRV8323RS (replaces all 12 IR2104s + reduces component count massively)
8x FS8205A dual MOSFETs
AT7456E OSD
ESP32 C3 WROOM 02 for AI link
MP1584EN buck regulator
2x XC6220B331 clean LDOs

the biggest change is the AI link. originally i was gonna put the raspberry pi on the drone but that would make it too heavy for the 0802SE motors. so the pi stays on the ground and the ESP32 on the drone handles the wireless link using ESP-NOW protocol which has under 2ms latency. way faster than wifi.
also half these components arent in kicad so had to make custom symbols again which took ages.
still gotta finish the schematic but its looking way more professional than before ngl

(the time is calculated based on how much total time im spending on each topic and not since the last journal cause i like to switch back and forth btw the things i do so whenever i feel like doing a journal i do it, random pic cause idk wt to put)





# 3/20/2026 11 PM - More research and custom symbols

_Time spent: 3.2h_

so i did more research found optimal components for the new board ig now it will be 26mm by 26mm and started making the schematic and half the components are not in kicad so made custom symbols.





# 3/20/2026 5 PM - Making a new version

_Time spent: 1h_

so i did some research and decided that ill make a new pcb which will feature a Flight Controller ESC Gyro OSD VTX Raspberry Pi UART so it will be a 6IN1 (idk wt img to use)                                         





# 3/20/2026 3 PM - Progress update

_Time spent: 4h_

Umm so i tried the integrated esc thing but umm its too big the pcb will be 50 by 50mm if i want to put everything on it so imma slpit it into 2 boards i finished the schematic doin the PCB's now 



# 3/20/2026 12 PM - couldnt find a symbol so had to make my own

_Time spent: 12.5h_


so ive decided to make a 6IN1 its gonna take a lot of time and i completed the esc part which took a lot of time cause i did it the hard way then i after i completed them i couldnt find a symbol whivh i needed then went to snapeda to find it and they didnt have the file too soo had to make my own wich also took a lot of time.






# 3/19/2026 9 PM - Looks like what i made was bs (the old one)

_Time spent: 4h_

making the onboard esc and adding a lot more things looks like this is gona take a lot more time than i thought so not to make anymore mistakes and trying to build a 5IN1 or a 6IN1 FC, tbh there is a lot of info i can find on a tiny whoop drone fc ( i couldnt i bet there is a lot of data out there ) so took me a quite a bit of time and my friend krish is helpin me so i got ntn to worry abt 





# 3/19/2026 2 PM - Completed PCB ( update - have to do the whole thing again )

_Time spent: 4.5h_

so did a lot of work it was pure hell since it was my first time i didn't know anything about traces i used only f.cu at first and one trace was blocking another, then my friend krish the GOAT came to help my ass again told me abt te via point and then i learned about b.cu, blasted through it, then came the errors which were a nightmare, had a lot of fun ngl. (update, it will fry before it will start -krish)(cause ill be using brushless motors and it dosent even have an esc)






# 3/19/2026 12 AM - added few more things to the FC

_Time spent: 1.5h_

umm did a lot more work ig ill complete the FC by tomorrow the finish the CAD, and ran the ERC got like 48 errors then dropped to 4 then to 1 i cant figure it out now will look at it tomorrow. 




# 3/18/2026 11 PM - Making the FC

_Time spent: 0.5h_

ummm so i just found out that i have to build my own FC crazy peak ill need to make all of the components onboard ive never built an FC before this is very new to me, but i do have my great friend krish with me helpin me out so huge credit to him. Decided to the FC first cause i have no idea on how to do it. 





# 3/18/2026 5 PM - making a new frame

_Time spent: 0.3h_

im currently designing a new frame for the drone which is very light and flexible so it can be fast and take some hits, this is a new design and ill be logging every 15mins to 1hr (i worked on it for 15mins but i cant but 0.25 in the how many hours did u spend so ill be reducing the time in the next journal)
 




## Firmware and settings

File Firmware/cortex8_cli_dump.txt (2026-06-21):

# Cortex-8 Betaflight CLI Dump
# Paste into Betaflight Configurator CLI after flashing firmware
# STM32H743BIT6 | 8-motor X8 Coaxial | DShot600 Bidir

# ============================================================
# BOARD
# ============================================================
board_name CORTEX8
manufacturer_id CX8

# ============================================================
# MOTOR PROTOCOL
# ============================================================
set motor_pwm_protocol = DSHOT600
set use_unsynced_pwm = OFF
set dshot_bidir = ON
set motor_poles = 14

# Motor output mapping — X8 Coaxial
# M1 Front Upper, M2 Front Lower
# M3 Right Upper, M4 Right Lower
# M5 Rear Upper,  M6 Rear Lower
# M7 Left Upper,  M8 Left Lower
set motor_count = 8

# ============================================================
# MIXER — X8 Coaxial
# ============================================================
mixer OCTOFLATH

# ============================================================
# GYRO
# ============================================================
set gyro_1_sensor_align = CW0
set gyro_2_sensor_align = CW0
set gyro_1_bustype = SPI
set gyro_1_spibus = 1
set gyro_1_spi_device = 1
set gyro_2_bustype = SPI
set gyro_2_spibus = 1
set gyro_2_spi_device = 2

# ICM-42688-P at 32kHz
set gyro_hardware_lpf = NORMAL
set gyro_lowpass_type = PT1
set gyro_lowpass_hz = 200
set gyro_lowpass2_type = PT1
set gyro_lowpass2_hz = 250

# ============================================================
# BLACKBOX
# ============================================================
set blackbox_device = SPIFLASH
set blackbox_rate_denom = 1
set blackbox_mode = NORMAL

# ============================================================
# SERIAL PORTS
# ============================================================
# UART1 — ESP32-S3 ELRS
serial 0 64 115200 57600 0 115200

# UART3 — OpenIPC Camera
serial 2 0 115200 57600 0 115200

# ============================================================
# BATTERY
# ============================================================
set battery_meter = ADC
set current_meter = ADC
set vbat_scale = 110
set current_meter_scale = 400
set current_meter_offset = 0
set ibata_hardware = 1

# 2S parallel default (7.4V), 4S series mode (14.8V)
set vbat_min_cell_voltage = 330
set vbat_warning_cell_voltage = 350
set vbat_max_cell_voltage = 420

# ============================================================
# RATES (Cortex-8 X8 Racing defaults)
# ============================================================
set rates_type = BETAFLIGHT
set roll_rc_rate = 100
set pitch_rc_rate = 100
set yaw_rc_rate = 100
set roll_expo = 0
set pitch_expo = 0
set yaw_expo = 0
set roll_srate = 70
set pitch_srate = 70
set yaw_srate = 70

# ============================================================
# PID — X8 Coaxial starting point
# X8 has higher inertia than standard quad — lower I gains
# ============================================================
set p_roll = 42
set i_roll = 85
set d_roll = 30
set f_roll = 90
set p_pitch = 46
set i_pitch = 90
set d_pitch = 32
set f_pitch = 95
set p_yaw = 45
set i_yaw = 90
set d_yaw = 0
set f_yaw = 90

# Anti gravity
set anti_gravity_gain = 5000

# ============================================================
# FEATURES
# ============================================================
feature -RX_PPM
feature -RX_SERIAL
feature TELEMETRY
feature LED_STRIP
feature OSD
feature -AIRMODE
feature ANTI_GRAVITY

# ============================================================
# LED STRIP
# ============================================================
# WS2812B on PC11
# Armed = green, Low battery = orange, Crash = red, Locator = blue
led 0 0,0::CH:0
led 1 0,0::CH:0
led 2 0,0::CH:0
led 3 0,0::CH:0

color 0 0,0,0
color 1 0,255,0
color 2 255,165,0
color 3 255,0,0
color 4 0,0,255

# ============================================================
# SAVE
# ============================================================
save

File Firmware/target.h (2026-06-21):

#pragma once

#define TARGET_BOARD_IDENTIFIER "CX8"
#define USBD_PRODUCT_STRING     "Cortex-8"

// ============================================================
// MCU
// ============================================================
// STM32H743BIT6 LQFP-208 @ 480MHz

// ============================================================
// LED & BEEPER
// ============================================================
#define LED0_PIN                PC11   // WS2812B data line
#define LED0_INVERTED

#define BEEPER_PIN              PC12
#define BEEPER_INVERTED

// ============================================================
// UART (Serial Ports)
// ============================================================
// UART1 — ESP32-S3 (ELRS / telemetry)
#define USE_UART1
#define UART1_RX_PIN            PA10
#define UART1_TX_PIN            PA9

// UART3 — OpenIPC camera
#define USE_UART3
#define UART3_RX_PIN            PB11
#define UART3_TX_PIN            PB10

// ============================================================
// SPI — IMU Bus (SPI1)
// ============================================================
#define USE_SPI
#define USE_SPI_DEVICE_1
#define SPI1_SCK_PIN            PA5
#define SPI1_MISO_PIN           PA6
#define SPI1_MOSI_PIN           PA7

// ============================================================
// IMU 1 — ICM-42688-P (Primary, 32kHz)
// ============================================================
#define USE_GYRO
#define USE_GYRO_SPI_ICM42688P
#define USE_ACC
#define USE_ACC_SPI_ICM42688P

#define GYRO_1_SPI_INSTANCE     SPI1
#define GYRO_1_CS_PIN           PB6
#define GYRO_1_EXTI_PIN         PI8
#define GYRO_1_ALIGN            CW0_DEG

// ============================================================
// IMU 2 — ICM-20602 (Backup / crash saturation recovery)
// ============================================================
#define USE_GYRO_SPI_ICM20602
#define USE_ACC_SPI_ICM20602

#define GYRO_2_SPI_INSTANCE     SPI1
#define GYRO_2_CS_PIN           PB7
#define GYRO_2_EXTI_PIN         PC1
#define GYRO_2_ALIGN            CW0_DEG

// ============================================================
// QSPI Blackbox Flash — W25Q128JW (128MB)
// ============================================================
#define USE_FLASHFS
#define USE_FLASH_W25Q128FV
#define FLASH_CS_PIN            PI3
#define FLASH_SPI_INSTANCE      SPI1

// Note: QSPI hardware pins PH13/PH14/PI0/PI1/PI2/PI3
// EasyEDA routes these to QUADSPI peripheral — configure in CubeMX

// ============================================================
// I2C — BQ25798 Charger
// ============================================================
#define USE_I2C
#define USE_I2C_DEVICE_1
#define I2C1_SCL_PIN            PB8
#define I2C1_SDA_PIN            PB9
#define I2C_DEVICE              (I2CDEV_1)

// ============================================================
// MOTOR OUTPUTS — DShot600 Bidirectional
// All 8 channels conflict-free across TIM5/TIM3/TIM1
// ============================================================
#define USE_MOTOR
#define USE_DSHOT

// X8 Coaxial motor mapping:
// M1 Front Upper  — PA0  TIM5_CH1  DMA1_Stream0
// M2 Front Lower  — PA1  TIM5_CH2  DMA1_Stream1
// M3 Right Upper  — PA2  TIM5_CH3  DMA1_Stream2
// M4 Right Lower  — PA3  TIM5_CH4  DMA1_Stream3
// M5 Rear Upper   — PB0  TIM3_CH3  DMA1_Stream4
// M6 Rear Lower   — PB1  TIM3_CH4  DMA1_Stream5
// M7 Left Upper   — PE9  TIM1_CH1  DMA2_Stream6
// M8 Left Lower   — PE11 TIM1_CH2  DMA2_Stream7

#define MOTOR1_PIN              PA0
#define MOTOR2_PIN              PA1
#define MOTOR3_PIN              PA2
#define MOTOR4_PIN              PA3
#define MOTOR5_PIN              PB0
#define MOTOR6_PIN              PB1
#define MOTOR7_PIN              PE9
#define MOTOR8_PIN              PE11

// ============================================================
// ARMING / SAFETY
// ============================================================
// Hardware arming inhibit via 74LVC1G32 OR gate
// STM32 pulls ARM_INHIBIT high to kill all 8 gate driver EN pins
#define USE_BUTTONS
#define BUTTON_A_PIN            PD0    // ARM_INHIBIT — JST-GH safety switch

// ============================================================
// BATTERY / ADC
// ============================================================
#define USE_ADC
#define ADC_INSTANCE            ADC1

// Current sensing via INA240A2 — analog output to ADC
#define CURRENT_METER_ADC_PIN   PC0
#define VBAT_ADC_PIN            PC3

#define USE_VOLTAGE_METER
#define USE_CURRENT_METER

// ============================================================
// BATTERY MATRIX CONTROL GPIOs
// ============================================================
// STM32 GPIOs for dual battery series/parallel switching
// PARALLEL_EN  — PC4  (default HIGH = parallel = 7.4V)
// SERIES_EN    — PC5  (pull HIGH to switch to series = 14.8V)
// PRECHARGE_EN — PC6  (fires 5ms before SERIES_EN)
// BAL_CTRL     — PC7  (mid-flight balancing control)
// CHARGE_EN    — PC8  (active LOW — enables BQ25798 charging)
// PD_PG        — PC9  (input — CH224K power good)
// SERIES_INH   — PC10 (input — TLV3201 overcurrent inhibit)

// ============================================================
// STATUS LEDs & RGB
// ============================================================
#define USE_LED_STRIP
#define LED_STRIP_PIN           PC11   // WS2812B DIN

// ============================================================
// CRASH LOCATOR / BACKUP SYSTEM
// ============================================================
// TPS3840 voltage supervisor monitors main VBAT
// On dropout → P-FET switches power to ESP32 automatically
// ESP32 handles BLE beacon independently — no STM32 involvement
// CHG_STAT     — PD1  (BQ25798 charge status input)
// CHG_INT      — PD2  (BQ25798 interrupt input)

// ============================================================
// SWD DEBUG
// ============================================================
// 4-pin 1.27mm header on top layer
// Pin 1 — VCC_3V3
// Pin 2 — PA13 SWDIO
// Pin 3 — PA14 SWCLK
// Pin 4 — DGND

// ============================================================
// WATCHDOG
// ============================================================
#define USE_WATCHDOG
// WWDG + IWDG both enabled — feed into arming inhibit line

// ============================================================
// BLACKBOX
// ============================================================
#define USE_BLACKBOX
#define BLACKBOX_DEVICE         BLACKBOX_DEVICE_FLASH
// 128MB W25Q128JW — circular buffer wear leveling in firmware

// ============================================================
// TARGET FEATURES
// ============================================================
#define TARGET_IO_PORTA         0xffff
#define TARGET_IO_PORTB         0xffff
#define TARGET_IO_PORTC         0xffff
#define TARGET_IO_PORTD         0xffff
#define TARGET_IO_PORTE         0xffff
#define TARGET_IO_PORTH         0xffff
#define TARGET_IO_PORTI         0xffff
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

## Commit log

2026-02-20 Add CAD design section to README
    Added CAD design section with assembly and component images.
2026-02-20 Update image reference for drone assembly
2026-02-20 Fix image filename for drone assembly in README
2026-02-20 Rename full assembly.png to full_assembly.png
2026-02-20 Rename prop guard.png to propguard.png
2026-03-16 Rename canopy-part.stl to 3D designs/canopy-part.stl
    [canopy-part.stl]
2026-03-16 Rename frame75mm.stl to 3D designs/frame75mm.stl
    [frame75mm.stl]
2026-03-16 Rename prop-guard.stl to 3D designs/prop-guard.stl
    [prop-guard.stl]
2026-03-16 Add CAD files
    [drone full assembly.f3d, drone full assembly.step]
2026-03-16 Add wiring diagram to README
    Added wiring diagram section with image to README.
2026-03-16 Update wiring diagram image in README
2026-03-16 Fix spelling of 'Bill of materials' to 'BOM'
    Corrected the spelling of 'Bill of materials' to 'BOM' in the README.
2026-03-16 Rename drone full assembly.step to drone full assembly.step
    [drone full assembly.step]
2026-03-16 Rename drone full assembly.f3d to drone full assembly.f3d
    [drone full assembly.f3d]
2026-03-17 Revise BOM with updated product information
    Updated BOM with new product prices and links.
2026-03-19 Rename Screenshot 2026-03-19 001209.png to schematic
2026-03-19 Rename Screenshot 2026-03-19 144904.png to PCB
2026-06-18 Rename Screenshot 2026-06-18 214209.png to BOTTOM-PCB
2026-06-18 Rename Screenshot 2026-06-18 214227.png to TOP-PCB
2026-06-18 Rename Screenshot 2026-06-18 214244.png to TOP-LAYER-TRACE
2026-06-18 Rename Screenshot 2026-06-18 214349.png to BOTTOM-LAYER-TRACE.png
2026-06-19 cheanged folder names
    [AI_Racing_Buddy_FC.kicad.sch]
2026-06-19 changes folder name
    [AI_Racing_Buddy_FC.kicad.sch]
2026-06-19 moved bom
2026-06-21 Rename Images/Screenshot 2026-06-21 083341.png to Images/Images/TOP-PCB-3D.png
2026-06-21 Rename Images/Images/TOP-PCB-3D.png to Images /TOP-PCB-3D.png
